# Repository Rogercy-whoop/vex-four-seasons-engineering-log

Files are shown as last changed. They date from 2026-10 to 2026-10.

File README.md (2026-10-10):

# VEX Robotics: four seasons, from newcomer to captain

**Four seasons of VEX V5 at my school, told through the robots, the code and the decisions.** I joined in Grade 9 carrying parts and filming matches, became the team's lead programmer in Grade 10, and have captained team **117V "Virtus Pro"** since Grade 11. This repository keeps the evidence: three generations of one robot and why each was replaced, every autonomous routine I wrote, the engineering notebook, the CAD, and what leading the team involved.

Yu Chen (Roger) · Grade 12 · Suzhou Foreign Language School (SFLS), China

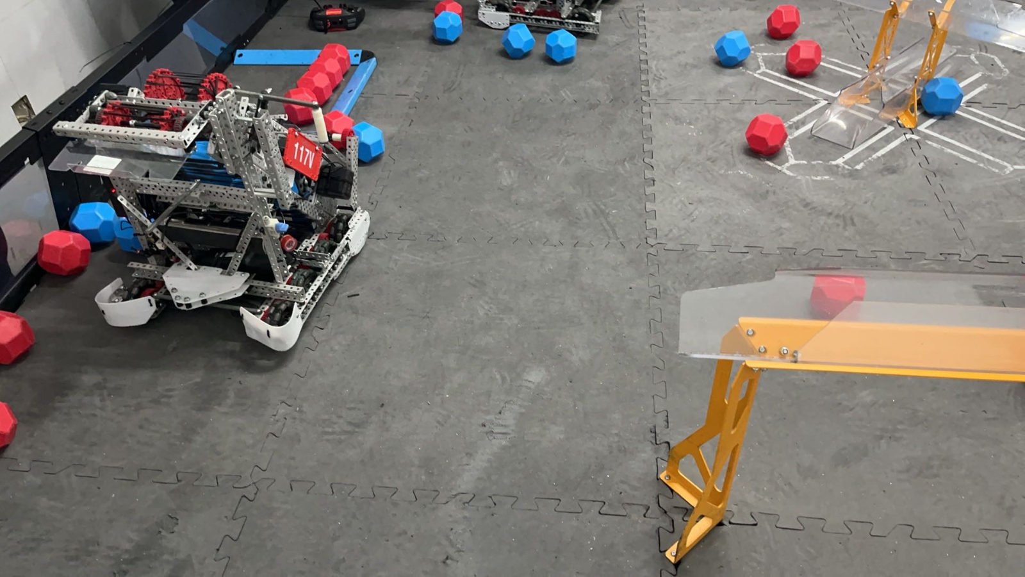
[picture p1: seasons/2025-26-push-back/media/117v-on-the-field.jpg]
117V's 2025–26 robot on the field


---

## Four seasons at a glance

| Season | Game | Team · my role | What we built | Highlight |
|---|---|---|---|---|
| 2023–24 · Grade 9 | *Over Under* | 117C · new member: parts, scouting, filming | Four versions of a catapult/climbing robot, V2.0 → V4.0 | Four robot versions in one season |
| 2024–25 · Grade 10 | *High Stakes* | 117C · **programmer → lead programmer**, CAD | Conveyor and lift-arm robot "V2.0" | 908 lines of autonomous code; a hand-written feedback controller for the lift arm |
| **2025–26 · Grade 11** | ***Push Back*** | **117V · captain, lead programmer, CAD** | **Three generations**: Gen 1 rollers → Gen 2 ramp → Gen 3 S-path | **Division 2 champion and overall runner-up**, VEX Robotics Invitational & VEX Academy National League (61 teams, 9 provinces); then the VEX World Championship China selection (Shanghai, Feb 2026) |
| 2026–27 · Grade 12 | *Override* | 117V · captain | In progress | Off-season: found why our drives never "arrived", and built a simulator now used by every team in the club |

## Start here

1. **[The 2025–26 design log](seasons/2025-26-push-back/design-log.md).** Three robots in one season. What each one got wrong, what we changed, and why, including the design we replaced even after it had won a competition.
2. **[The autonomous code](seasons/2025-26-push-back/code/README.md).** How the routes were planned, how they changed after real matches, and how the code grew and was cut back.
3. **[Reading our control template line by line](https://github.com/Rogercy-whoop/vex-auton-visualizer/blob/main/docs/FINDINGS.md)** (July 2026). The discovery that, all through 2025–26, every drive move had been ending on its timeout, never on arrival.

---

## The story

**Grade 9: learning the machine.** I joined the SFLS robotics club in 2023, on team 117C. My jobs were sourcing parts, scouting other teams and filming matches. That season the club's robot went through four versions (V2.0, V2.5, V3.0, V4.0), changing the drive speed, the scoring and climbing mechanisms, and the motor budget along the way. Each version was documented as a step-by-step build guide. → [2023–24](seasons/2023-24-over-under/README.md)

**Grade 10: writing the code.** In 2024–25 I became the team's programmer, then its lead programmer. Between March and May 2025 our autonomous code grew from 699 to 908 lines, with separate routines for attacking and defending, for qualification and final matches, and for skills. I also wrote a feedback controller of my own: a proportional loop that drives the lift arm to 37° from a rotation sensor. With our mentor I modelled the robot in SolidWorks. → [2024–25](seasons/2024-25-high-stakes/README.md)

**Grade 11: captain, and three robots.** In 2025–26 I captained 117V. We built **Gen 1**, found it could not store enough blocks and that its rubber-band rollers tangled with other robots, and replaced it with **Gen 2**: a new drivetrain, a rubber-wheel intake on a floating rail, double-row storage and a belt-and-paddle transfer. In August our club's sister team 117B took a robot of the Gen 2 design to the WRCT 2025 selection and won the high-school division; I helped them during development, in the pits and with their code. Watching that design compete showed us three problems: blocks leaking from the double row, an autonomous with no real advantage, and side-by-side jams. So we rebuilt ours as **Gen 3**, with a single S-shaped storage channel and rollers deliberately run at different speeds. In November, Gen 3 **won Division 2 and finished runner-up overall** at a national invitational in Suzhou. During that event I explained a disputed result to the referees on my own, in my second language; they ordered a rematch, and we won it. In February we competed at the VEX World Championship China selection in Shanghai. → [2025–26](seasons/2025-26-push-back/README.md) · [leadership, in my own words](leadership.md)

**After the season: finding out why.** After two seasons of tuning autonomous routines by trial and error, in July 2026 I read our coach's motion-control template line by line. I found that every drive move that season had been ending on its timeout, never on arrival. Then I built a simulator that runs our real code on a laptop; all four teams in the club now use it. → [vex-auton-visualizer](https://github.com/Rogercy-whoop/vex-auton-visualizer)

**Grade 12.** Captain again, for *Override*. The robot is paused while the team applies to university. → [2026–27](seasons/2026-27-override/README.md)

---

## Inside this repository

| | |
|---|---|
| **Design** | [2025–26 design log](seasons/2025-26-push-back/design-log.md) · [engineering notebook and design documents](seasons/2025-26-push-back/notebook/README.md) · [CAD](seasons/2025-26-push-back/cad/README.md) · build guides for [2023–24](seasons/2023-24-over-under/README.md) and [2024–25](seasons/2024-25-high-stakes/README.md) |
| **Code** | [2025–26 autonomous routines](seasons/2025-26-push-back/code/README.md) · [2024–25 code and the arm controller](seasons/2024-25-high-stakes/README.md#code) |
| **Leadership** | [What being captain involved, and what it changed in me](leadership.md) |
| **Who did what** | [ROLES.md](ROLES.md): my part, my teammates' parts, our mentor's |
| **Beyond VEX** | [How VEX led to my other projects](beyond-vex.md) |
| **Photos** | [Robot photos](media.md) |

## How this repository was made

The robots, CAD, code and decisions are the team's and mine, as broken down in [ROLES.md](ROLES.md). Our notebook and design documents are published as originals, in Chinese. The English translations and summaries, the page structure and the first drafts of the text were written with Claude, Anthropic's AI assistant, from those documents; see [AI-USE.md](AI-USE.md). Published with the agreement of my teammates and our mentor.

**Not included, on purpose:** other teams' code; the coach's motion-control template (linked, not copied); VEX's part library and field CAD.

**Licence:** code under [MIT](LICENSE); documents, notebooks, CAD and photos under [CC BY-NC 4.0](LICENSE-CONTENT.md).

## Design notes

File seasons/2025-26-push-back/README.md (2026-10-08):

# 2025–26 *Push Back* (Grade 11): team 117V, captain

**Division 2 champion and overall runner-up** at the 2025–26 VEX Robotics Invitational & VEX Academy National League (Suzhou, November 2025; 61 teams from 9 provinces). Then the VEX World Championship China selection (Shanghai, February 2026).

117V on the field

## The season

This was my first season as captain. Team 117V had six members, and I was the lead programmer: I wrote every autonomous routine. With our mentor I also built the robot's SolidWorks models.

We built three robots. **Gen 1** could not store enough blocks, and its rubber-band rollers tangled with other robots. **Gen 2** fixed both with a new drivetrain, a rubber-wheel intake on a floating rail, double-row storage and a belt-and-paddle transfer.

In August our club's sister team 117B took a robot of the Gen 2 design to the WRCT 2025 selection and won the high-school division. While upgrading our own robot to Gen 2, I helped them during development, in the pits and with their code. Watching the design compete showed us that the double row leaked blocks, the autonomous had no real advantage, and blocks jammed side by side. So we designed **Gen 3**: a single S-shaped channel, three rollers deliberately run at different speeds, and a PC plate that centres the robot on the goal. In November, Gen 3 won Division 2 in Suzhou and reached the final.

The full reasoning, decision by decision, is in the **[design log](design-log.md)**.

## In this folder

| | |
|---|---|
| [design-log.md](design-log.md) | Every design decision, Gen 1 → Gen 2 → Gen 3, with reasons and evidence |
| [code/](code/README.md) | The autonomous routines (C++): strategy, how they changed, how the code grew and was cut back |
| [notebook/](notebook/README.md) | The full engineering notebook, the season improvement record, the concept study and the build guides (originals in Chinese, summarised in English) |
| [cad/](cad/README.md) | Our custom SolidWorks parts |
| [media/](media/) | Renders and photos |

## Timeline

| When | What happened | Robot |
|---|---|---|
| Start of the season | Concept study and brainstorm; ramp robot chosen; Gen 1 built and tested | Gen 1 |
| Jul–Aug 2025 | Gen 2 built; its autonomous code written | Gen 2 |
| 16 Aug 2025 | WRCT 2025 selection: our sister team 117B wins the high-school division with a Gen 2-design robot; I helped in development, in the pits and with code. Three problems with the design found. | Gen 2 |
| 22–24 Aug 2025 | Huzhou invitational ([RE-V5RC-25-0863](https://events.vex.com/robot-competitions/vex-robotics-competition/RE-V5RC-25-0863.html)): 29th of 54 ([photos](../../media.md#huzhou-invitational-august-2025)) | Gen 2 |
| Aug–Nov 2025 | Gen 3 designed and built | Gen 3 |
| **21–23 Nov 2025** | **Suzhou: Division 2 champion, overall runner-up** (below) | Gen 3 |
| Dec 2025 – Jan 2026 | Autonomous routines refined; Kunshan event ([RE-V5RC-26-4036](https://events.vex.com/robot-competitions/vex-robotics-competition/RE-V5RC-26-4036.html)) | Gen 3 |
| 1–4 Feb 2026 | **VEX World Championship China selection**, Shanghai (科创青禾 全国VEX机器人精英赛暨VEX世锦赛中国选拔赛, [RE-V5RC-25-0839](https://events.vex.com/robot-competitions/vex-robotics-competition/RE-V5RC-25-0839.html)): 34th of 40 in our division | Gen 3 |

## Suzhou, 21–23 November 2025

*2025-2026 VEX 机器人邀请赛暨VEX学苑全国联赛* (VEX Robotics Invitational & VEX Academy National League), high-school V5, Suzhou Olympic Sports Center. The event was open to teams from across China, and its stated purpose was to select teams for the VEX World Championship China selection. **61 teams from 9 provinces and municipalities** took part, in two divisions; each division's elimination winner went to the final. Official record: [RE-V5RC-25-3593](https://events.vex.com/robot-competitions/vex-robotics-competition/RE-V5RC-25-3593.html).

**Qualification (Division 2, 31 teams):** 9th, 5 wins and 3 losses.

**Eliminations**, allied with team **14882Z**:

| Round | Opponents | Score |
|---|---|---|
| Round of 16 | 18964W + 1418C | **won** 94–20 |
| Quarterfinal | 93333C + 58888A | **won** 47–43 |
| Semifinal | 33398A + 1418A | **won** 46–38 |
| **Division 2 final** | 41999C + 3778D | **won** 56–15 |
| Final, match 1 | 18965J + 5138K | **won** 47–26 |
| Final, match 2 | 18965J + 5138K | lost 22–60 |
| Final, match 3 | 18965J + 5138K | lost 3–110 |

**Award: Tournament Finalists (runner-up).**

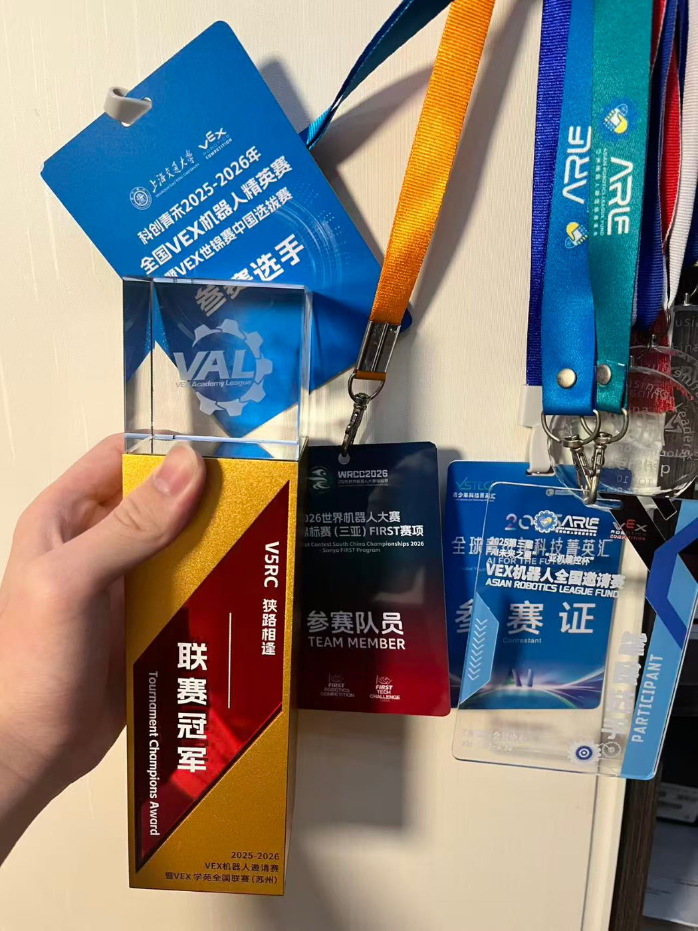
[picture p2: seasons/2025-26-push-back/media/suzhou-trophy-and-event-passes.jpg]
Our trophy from Suzhou, with passes from the season's events


*Our trophy from Suzhou, with passes from the season's events, including the VEX World Championship China selection in Shanghai and the Huzhou and Kunshan invitationals.*

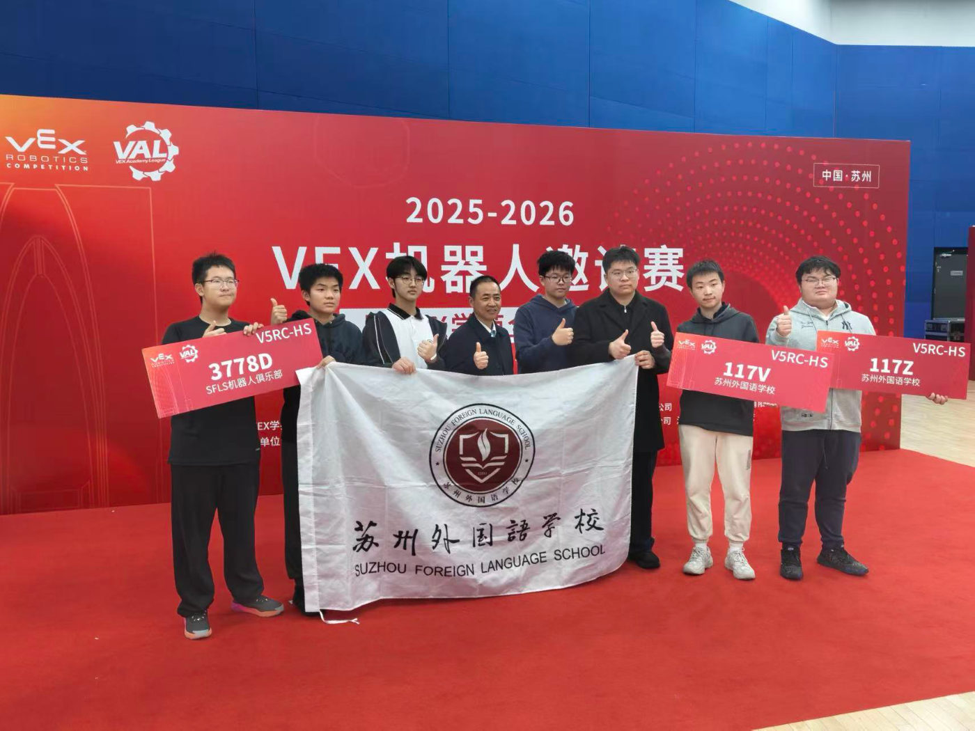
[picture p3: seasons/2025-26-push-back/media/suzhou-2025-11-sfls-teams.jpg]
SFLS teams at Suzhou


*Our school's teams at Suzhou: 117V with sister teams 117Z and 3778D, and our teacher.*

During the event, a result was disputed. I explained our case to the referees on my own, in my second language. They ordered a rematch, and we won it. (The online record shows only the final result of each round.) → [leadership](../../leadership.md)

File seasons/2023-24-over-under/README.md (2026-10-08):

# 2023–24 *Over Under* (Grade 9), team 117C

I joined the SFLS robotics club this year. As a new member I sourced parts, scouted other teams and filmed matches.

## One robot, four versions

The club's robot this season went through four versions. Each was documented as a step-by-step build guide in Feishu, with CAD renders, written by our mentor and the team.

| Version | What changed | Guide |
|---|---|---|
| **V2.0** | 360 rpm drive; built in a catapult variant and a climbing variant | [v2.0.pdf](build-guides/v2.0.pdf) |
| **V2.5** | Slower, stronger drive: 6 motors at 36:84 → 257 rpm on 6 wheels. Catapult on a 5:1 reduction, a 600 rpm direct-drive intake, a side climb, twin-piston wings. | [v2.5.pdf](build-guides/v2.5.pdf) |
| **V3.0** | A 55 W design | [v3.0.pdf](build-guides/v3.0.pdf) |
| **V4.0** | Climbing robot built around 5.5 W motors, on 4 in wheels | [v4.0.pdf](build-guides/v4.0.pdf) |

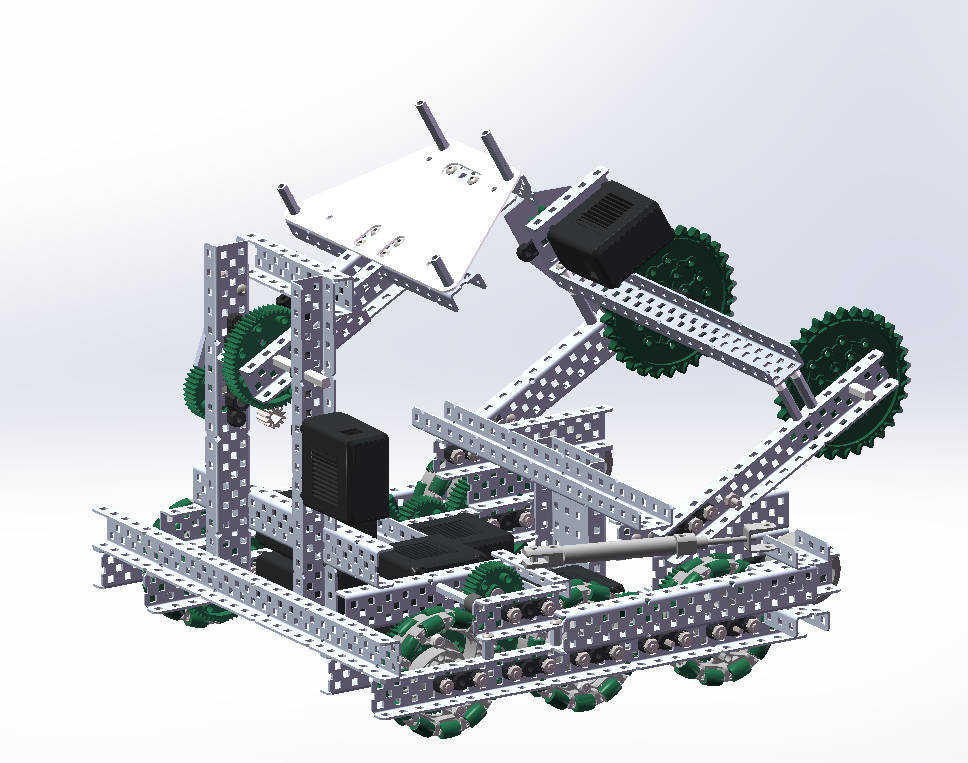
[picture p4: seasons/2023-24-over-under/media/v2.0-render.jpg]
V2.0
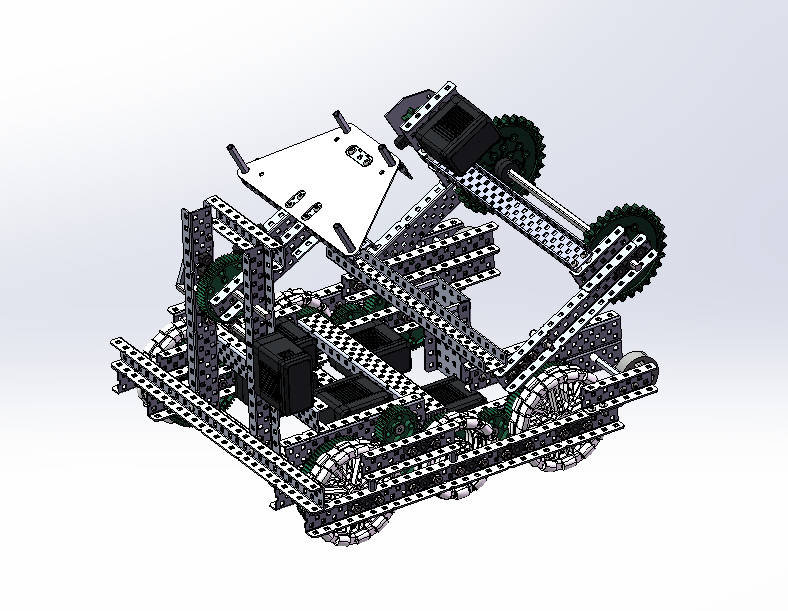
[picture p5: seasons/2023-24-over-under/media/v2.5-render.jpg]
V2.5
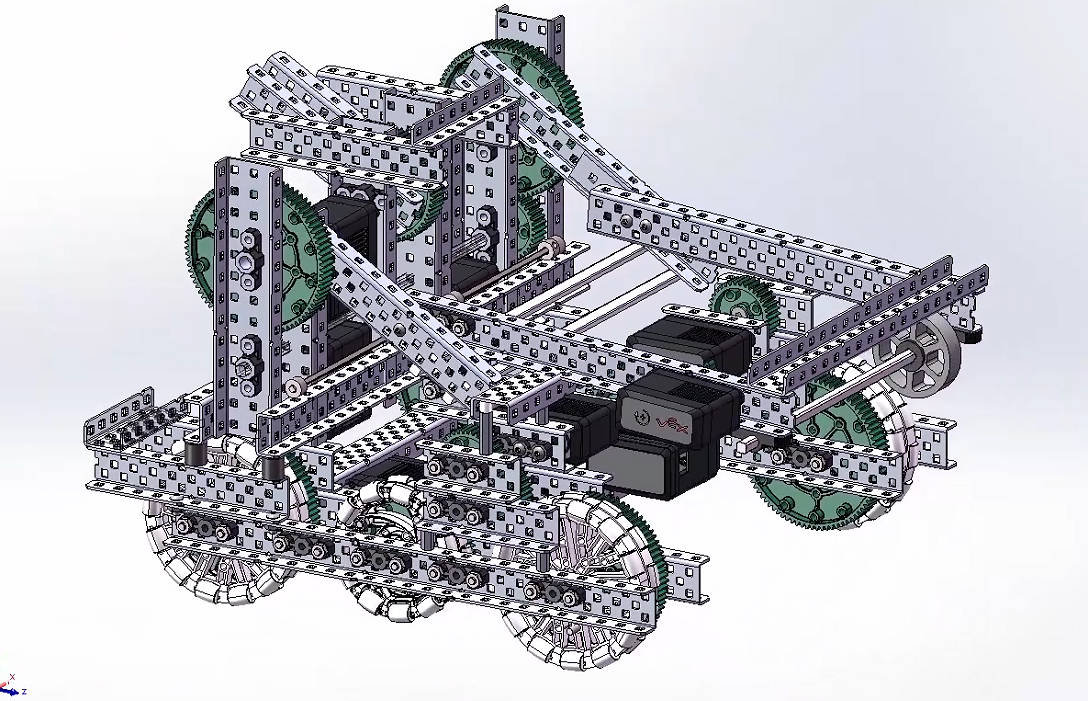
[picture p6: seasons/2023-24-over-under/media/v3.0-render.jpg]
V3.0
|  |  |  |
|---|---|---|
| V2.0 | V2.5 | V3.0 |

*The original guides were split into chapters (chassis, intake, climb, latch, launcher) for each variant. For this repository each version's chapters were merged into one PDF, and duplicate chapters shared by two variants were kept once. No content was changed.*

**Next season →** [2024–25: writing the code](../2024-25-high-stakes/README.md)

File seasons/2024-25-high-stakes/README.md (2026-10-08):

# 2024–25 *High Stakes* (Grade 10), team 117C

This was the season I started programming. I became the team's programmer and then its lead programmer, and with our mentor I modelled the robot in SolidWorks.

## The robot: "V2.0"

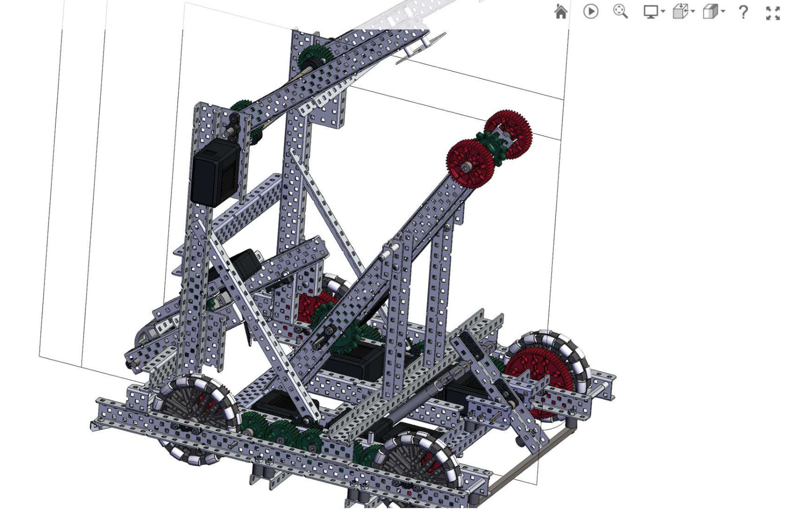
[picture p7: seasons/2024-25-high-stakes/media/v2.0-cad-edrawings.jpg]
V2.0 in SolidWorks eDrawings


*The "V2.0" model (SolidWorks, eDrawings web export, December 2024): a conveyor with hooks, a lift arm on 84T gears, and a 2 in rubber-wheel intake.*

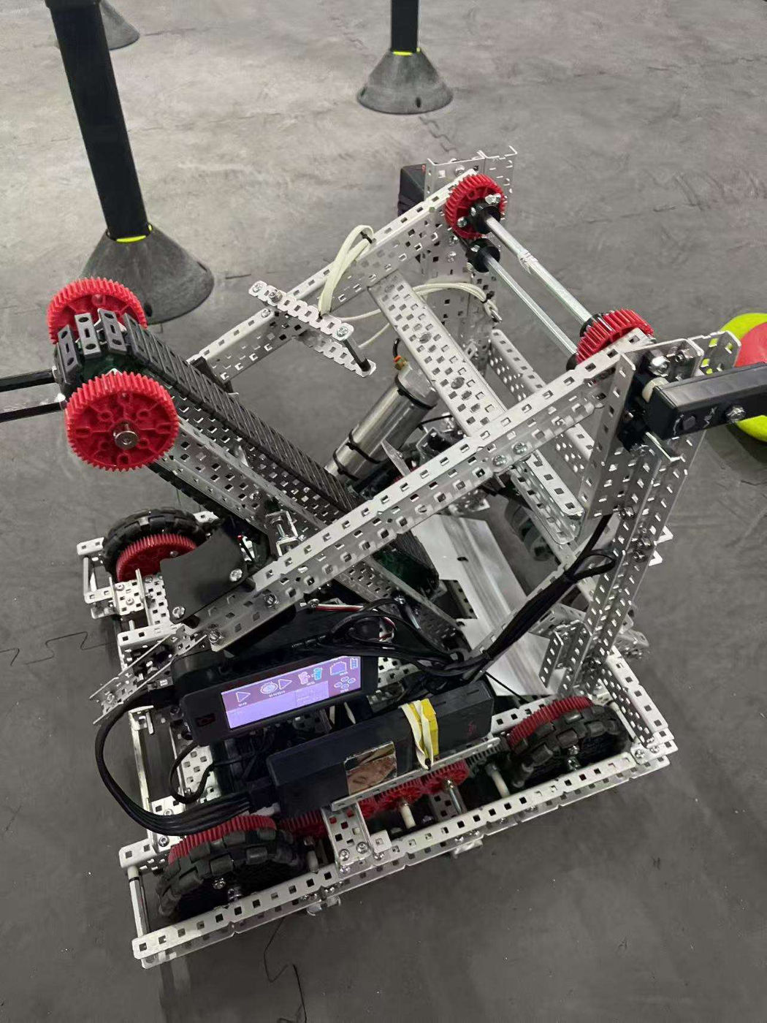
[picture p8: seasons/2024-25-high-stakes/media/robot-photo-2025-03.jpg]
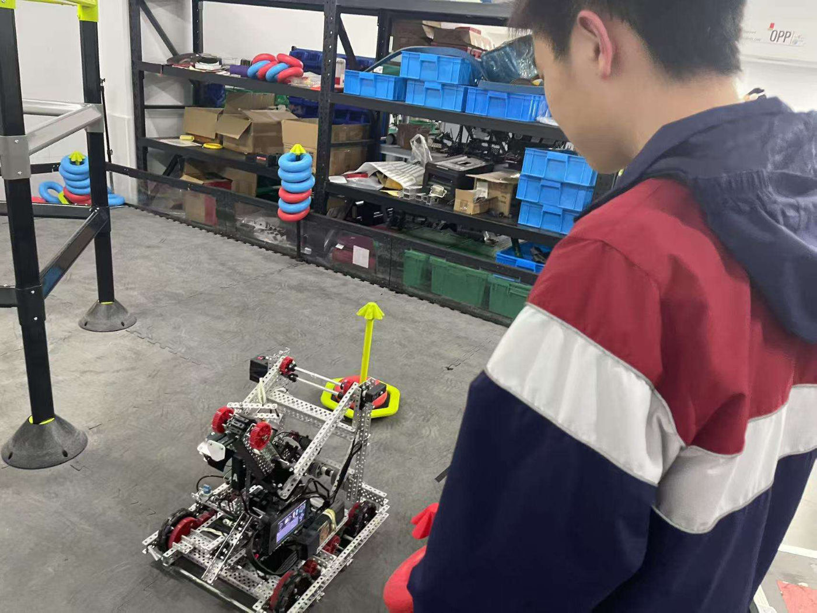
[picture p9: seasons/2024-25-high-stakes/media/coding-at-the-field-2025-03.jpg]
|  |  |
|---|---|
| *The built robot, March 2025* | *Testing code at the field, March 2025* |

The robot was documented as step-by-step build guides, co-written by our mentor, my teammates and me: [chassis](build-guides/01-chassis.pdf), [intake](build-guides/02-intake.pdf), [conveyor](build-guides/03-conveyor.pdf) and [lift arm](build-guides/04-lift-arm.pdf).

## Code

The project, "117c", grew from 699 lines of autonomous code in early March 2025 to **908 lines** by late May. Alongside left- and right-side routines, I wrote separate ones for attacking and defending, for qualification and final matches, and for skills.

| File | Lines | What it is |
|---|---|---|
| [`code/autons.cpp`](code/autons.cpp) | 908 | All the autonomous routines |
| [`code/autofunction.cpp`](code/autofunction.cpp) | 113 | Arm, intake and drive helpers |
| [`code/user.cpp`](code/user.cpp) | 95 | Driver control |
| [`code/main.cpp`](code/main.cpp) | | Competition set-up, the auton selector, and the arm controller below |

### A feedback controller for the lift arm

For the lift arm I wrote a proportional controller that reads a rotation sensor and drives the arm to 37° at the press of a button (`arm()` in [`main.cpp`](code/main.cpp)):

```cpp
error_a = t_angle - pre_angle;      // t_angle = 37 degrees
speed = 20 + error_a * p;           // p = 0.8: constant base power plus a correction proportional to the error
climb.spin(fwd, speed, pct);
...
if (fabs(pre_angle - t_angle) < 2.5 and Tarm > 350) break;   // within 2.5 degrees, after 350 ms
```

It also handles the sensor reading wrapping past 360° back to 0°.

**Next season →** [2025–26: captain, and three robots](../2025-26-push-back/README.md)

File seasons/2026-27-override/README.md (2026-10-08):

# 2026–27 *Override* (Grade 12): team 117V, captain

Work on this season's robot is paused while the team applies to university. This page will grow when it resumes.

## Between seasons

- **July 2026: reading the template.** After two seasons of tuning autonomous routines by trial and error, I read our coach's motion-control template line by line. I found that every drive move in 2025–26 had ended on its timeout, never on arrival, and that the odometry had never been switched on. → [FINDINGS.md](https://github.com/Rogercy-whoop/vex-auton-visualizer/blob/main/docs/FINDINGS.md)
- **August–October 2026: building the simulator.** It runs a team's real, unmodified code on a laptop and shows where each move actually ends, cutting each test from 5–10 minutes to about 2 seconds. All four teams in our club now use it. → [vex-auton-visualizer](https://github.com/Rogercy-whoop/vex-auton-visualizer)

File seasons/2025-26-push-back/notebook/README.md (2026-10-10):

# 2025–26 notebook and design documents

The originals are in Chinese and are kept complete and unedited. Each has an English summary below. To keep every file under 10 MB, the photos inside the PDFs were downscaled (longest side 1400 px) and re-saved as JPEG. Text, handwriting and drawings are untouched.

| File | What | Pages | Size | Written by |
|---|---|---|---|---|
| [2025-26-engineering-notebook.pdf](2025-26-engineering-notebook.pdf) | Engineering notebook (*工笔*), iPad handwriting | 20 | 9.4 MB (from 28.2) | The team |
| [2025-26-improvement-record.pdf](2025-26-improvement-record.pdf) | Season improvement record (*25-26赛季机器改进记录*), Gen 1 → Gen 2 → Gen 3 | 22 | 2.2 MB | Our mentor, my teammates and me |
| [2025-26-concept-study.pdf](2025-26-concept-study.pdf) | Concept study (*机型设计参考*) from the start of the season | 5 | 0.6 MB | Our mentor, my teammates and me |
| [build-guides/](build-guides/) | Step-by-step build guides for Gen 1 and Gen 2 | 2–25 each | 0.1–2.1 MB | Our mentor, my teammates and me |

## 1. Engineering notebook (*工笔*), summary

| Pages | Content |
|---|---|
| 1 | Cover: "117V Virtus PRO" with a line drawing of the robot |
| 2 | The six team members and their roles (see [ROLES.md](../../../ROLES.md)) |
| 3–7 | **Understanding the rules.** 88 blocks (preloads, match loads, field, loaders), goals and their capacities, scoring values, parking, the 5-second delayed scoring. **Motor budget:** total power ≤ 88 W, so the legal mixes of 11 W / 5.5 W motors are 8+0, 7+2, 6+4, 5+6, 0+16. The principle: use one motor for several jobs where possible, and don't add motors just to reach 88 W. Non-VEX parts (rope ≤ 6.35 mm, PVC sheet), the 18 in starting size, how WP/AWP/SP rankings work. The conclusion: *"autonomous matters most. Winning it eases the pressure on driver control and is the key to ranking."* |
| 8–9 | **Brainstorm.** Lift robot (simple, low centre of gravity, passes under the long goal; but unstable while scoring and drops stored blocks) vs "big stomach" robot (stores the most and is stable; but heavy and wide, and gets stuck turning between goals) vs **ramp robot** (agile, enough storage, front intake / rear scoring suits loader → long goal; but weaker grip and less pushing power). **Final choice: ramp robot.** It had no major weakness and balanced storage against agility. |
| 10–12 | **Problems → fixes:** long-goal alignment (a PVC plate plus an aluminium guide that self-centres the robot), middle-goal descoring, two-at-a-time jams (PVC funnel), blocks stopping on the loader plate (a zip tie) |
| 13–16 | **Robot design:** front intake / rear scoring; which roller turns which way for the high, middle and low goals; the first rubber-band rollers stored only 4 blocks; extra bands stiffened the top roller for the middle goal; band rollers → rubber wheels; chain moved inside and protected by a crossbeam |
| 17–20 | **Autonomous:** priorities (task > points > driver-control head start), the AWP task, left route v1 → v2 (long goal first), right route (drop the middle goal). See [code/README.md](../code/README.md#planning-the-15-seconds). |

**Third-party figures.** Pages 3–5 and 12 reproduce figures from the official VEX V5RC *Push Back* game manual, and pages 17–20 draw routes on a *Push Back* field image. They are used inside a student notebook to analyse the rules. They remain © VEX Robotics / REC Foundation and are not covered by this repository's licence. The official manual: [the REC Foundation knowledge base](https://v5rc-kb.recf.org/hc/en-us/articles/9652912628631-Game-Manual-and-Resources-for-VEX-V5-Robotics-Competition-Teams).

## 2. Season improvement record, summary

Gen 1 → Gen 2 → Gen 3 with SolidWorks renders and test photos. Summarised card by card in the [design log](../design-log.md).

## 3. Build guides

| File | Summary |
|---|---|
| [gen1-chassis.pdf](build-guides/gen1-chassis.pdf) (*V1.0 机器搭建*, 8 p) | Gen 1 chassis: **29 holes wide**, bearing and motor positions, wheel shaft stack-up |
| [gen1-intake.pdf](build-guides/gen1-intake.pdf) (*吸取搭建*, 16 p) | Gen 1 roller intake: 5.5 W + 11 W motors, shaft lengths (30.4 / 25.4 / 26.7 / 27.9 cm), sprocket and spacer order |
| [gen2-chassis.pdf](build-guides/gen2-chassis.pdf) (*v2.0 机器搭建*, 15 p) | Gen 2 chassis: **27 holes wide** between the 30-hole rails, 36T gears × 10, 3.25 in omni wheels × 4 |
| [gen2-intake.pdf](build-guides/gen2-intake.pdf) (*搭建intake*, 25 p) | Gen 2 intake: uprights, cut C-channels, PC plates, two sprocket stages, the "intake up" assembly, descore mount |
| [gen2-pneumatics.pdf](build-guides/gen2-pneumatics.pdf) (*气动装置搭建*, 7 p) | Side hook and loader pistons: drilling positions and lengths |
| [gen2-middle-goal-plate.pdf](build-guides/gen2-middle-goal-plate.pdf) (*中goal 板子制作*, 6 p) | Middle-goal PC plate: 90° bend at 30 mm, 30° bend at 15 mm, zip-tie holes |
| [gen2-sled.pdf](build-guides/gen2-sled.pdf) (*Sled 安装*, 2 p) | Sled mounting |

*简单底盘搭建* ("simple chassis") is the first half of *v2.0 机器搭建*, so it is not repeated.

## Not included

- *2025-2026 规则解读* (rules interpretation): a teaching handout made mostly of game-manual images, with nothing of ours to add. The official manual is linked above.

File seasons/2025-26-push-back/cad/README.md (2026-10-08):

# 2025–26 CAD (SolidWorks)

I built this season's SolidWorks models with our mentor. The renders in the [design log](../design-log.md) come from them.

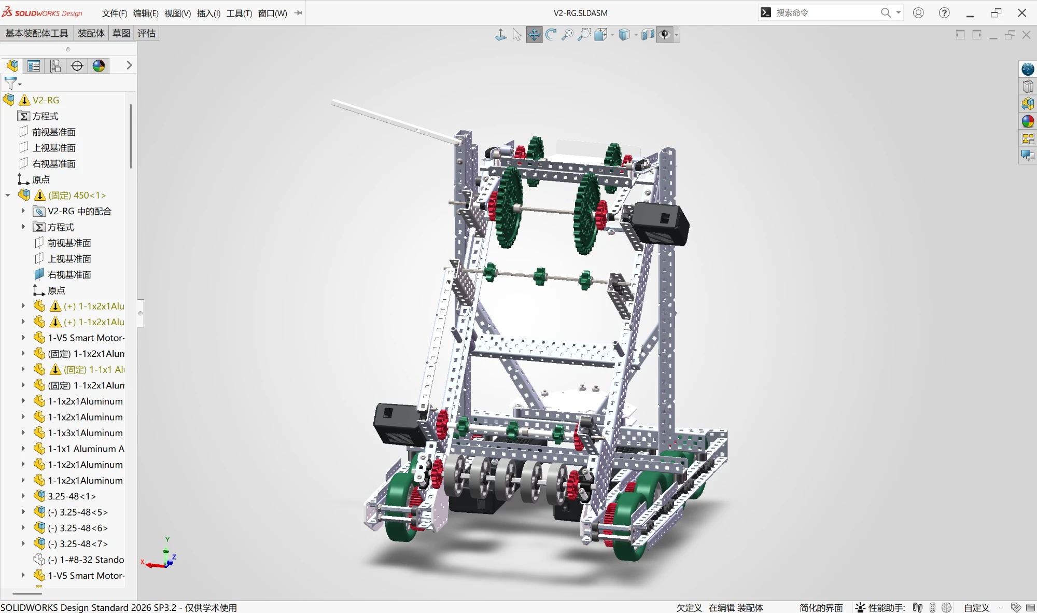
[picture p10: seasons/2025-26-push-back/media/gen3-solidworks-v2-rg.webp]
Gen 3 in SolidWorks


*The Gen 3 assembly (`V2-RG`) in SolidWorks.*

## Custom parts (in this repository)

These are the parts we drew ourselves, as opposed to VEX library parts. They open in SolidWorks or the free eDrawings Viewer.

| File | What it is |
|---|---|
| [`parts/对位板3.SLDPRT`](parts/) | **Centring plate, version 3.** The PC plate shaped from the goal's triangular notch, which replaced the aluminium triangle that centred badly ([design log](../design-log.md#lining-up-aluminium-triangle--pc-centring-plate)) |
| [`parts/sled-V2.SLDPRT`](parts/) | Sled plate, version 2 |
| [`parts/de.SLDPRT`](parts/) | Custom part |
| [`parts/侧钩粗轴.SLDPRT`](parts/) | High-strength shaft for the side hook |
| [`parts/17孔粗轴.SLDPRT`](parts/) | 17-hole high-strength shaft |
| [`parts/support.SLDPRT`](parts/) | Support |
| [`parts/窄轴承座.SLDPRT`](parts/) | Narrow bearing block |

## Assemblies

The full assemblies, including the Gen 3 robot (`V2-RG`) and the descore arm, are not committed. They are large (up to 28 MB), and they only open together with VEX's part library, which VEX distributes itself ([VEX CAD resources](https://v5rc-kb.recf.org/hc/en-us/articles/9636477857687-CAD-for-VEX-Robotics-Competition-Teams)).

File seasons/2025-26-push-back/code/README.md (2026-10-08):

# 2025–26 autonomous code

I wrote every autonomous routine for 117V this season, in C++ with VEXcode Pro V5. A second programmer on the team was learning and assisted me.

| File | Lines | What it is |
|---|---|---|
| [`autons.cpp`](autons.cpp) | 392 | Every autonomous routine, and the PID gains and exit conditions they run with |
| [`autofunction.cpp`](autofunction.cpp) | 82 | Helpers the routines call: collect and store, score high, score in the middle goal, stop |
| [`user.cpp`](user.cpp) | 83 | Driver control: drive, intake and scoring buttons, piston toggles |

**Not mine:** the motion-control template underneath (PID, drive functions, odometry) was supplied by our coach. It is not copied here; it is credited file by file in the simulator repo's [ATTRIBUTION.md](https://github.com/Rogercy-whoop/vex-auton-visualizer/blob/main/ATTRIBUTION.md).

## Planning the 15 seconds

The notebook sets the order of priorities for autonomous (NB p.17):

> **complete the autonomous task > score autonomous points > set up an advantage for driver control**

- **The task** (the AWP conditions) needs both robots: at least 7 alliance blocks scored, blocks in three goals, 3 blocks taken out of a loader, neither robot touching the park zone. We aimed to complete as much of it as our robot could.
- **Points:** the preload, 3 field blocks and 3 loader blocks guarantee 7.
- **The advantage:** whoever holds the control zone at the end of autonomous starts driver control ahead, so the route should take it (NB p.18).

## Changing the routes after real matches

Two changes came from competition, not from planning (NB p.19–20):

- **Left side: long goal first.** Our first left route scored the middle goal first. In real matches the opponent was scoring the same middle goal at the same time and interfered. The second version scores the long goal first and reaches the middle goal *after* the opponent, so it still scores there and can also knock the opponent's blocks out.
- **Right side: drop the middle goal.** On the right the middle goal is the low one. Scoring it means reversing the intake to push blocks out of the front, which cost too much time and was hard to do. So all 7 blocks go into the long goal: field blocks → loader → score → take the control zone.

| Routine | What it is |
|---|---|
| `zuo` | Left side, first version |
| `superzuo` | Left side, revised: long goal first |
| `lanyou` | Right side: all seven blocks into the long goal |
| `superyou` | Right side, alternative route |
| `skillszuo` | Skills: four loader visits, each emptied into a long goal |
| `test` | Single moves for tuning |

## How the code grew, and was cut back

| Version | Date | `autons.cpp` | |
|---|---|---|---|
| Gen 2 | Aug 2025 | 262 lines | First routines for the ramp robot |
| Gen 3, "strongest version" | 5 Dec 2025 | 559 lines | Many experimental routes tried side by side |
| Gen 3, competition | 3 Feb 2026 | **392 lines** | Pruned to the six routines above |

## What I found later

All season, the drive moves were tuned by adjusting their timeouts. In 2024–25 our code let a drive end when it arrived within 1.5 in. In 2025–26 that settle band was set to 0. In July 2026 I read our coach's template line by line and found what that meant: the "arrived" test can never be true at 0, so **every drive move in 2025–26 ended on its timeout, never on arrival**. The timeout, not the distance, decided how far the robot went. I also found that the odometry had never been switched on.

That investigation led to the simulator I built next. → **[vex-auton-visualizer / FINDINGS.md](https://github.com/Rogercy-whoop/vex-auton-visualizer/blob/main/docs/FINDINGS.md)**

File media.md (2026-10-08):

# Photos

## 2025–26 *Push Back*, team 117V

### Suzhou, November 2025

Trophy and event passes
*Our trophy from Suzhou, where we were Division 2 champions and overall runner-up, with passes from the season's events.*

SFLS teams at Suzhou
*Our school's teams at the Suzhou event: 117V with sister teams 117Z and 3778D, and our teacher.*

### The robot

117V on the field
*117V on the field, next to a loader.*

Gen 3 in SolidWorks
*The Gen 3 assembly in SolidWorks.*

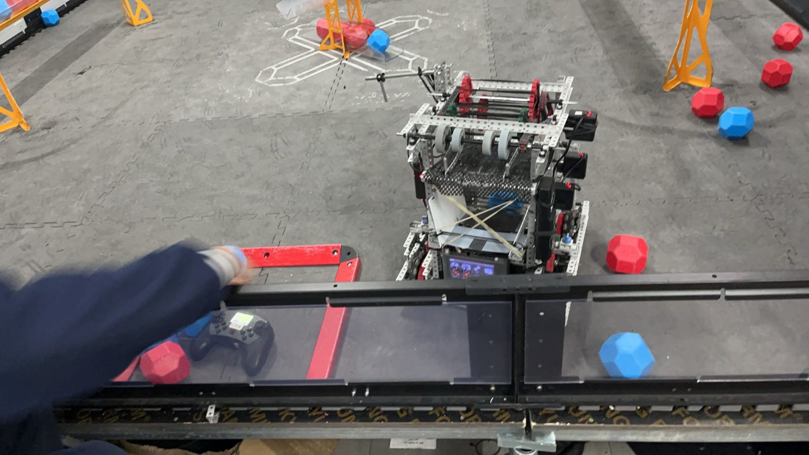
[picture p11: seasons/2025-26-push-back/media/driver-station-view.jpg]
From the driver station

*From the driver station during practice.*

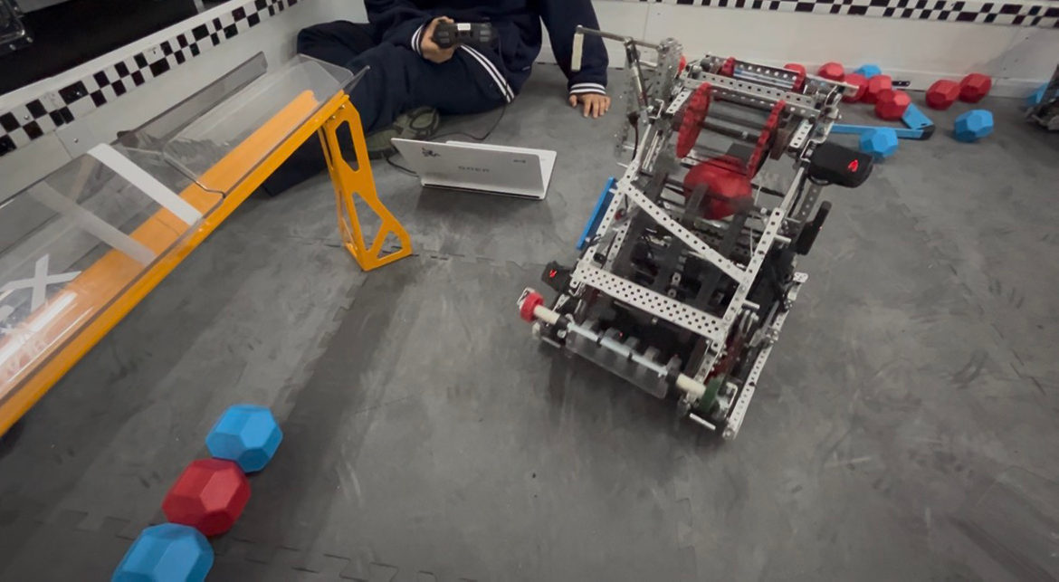
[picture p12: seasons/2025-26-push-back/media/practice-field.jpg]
On the practice field

*Testing on our practice field.*

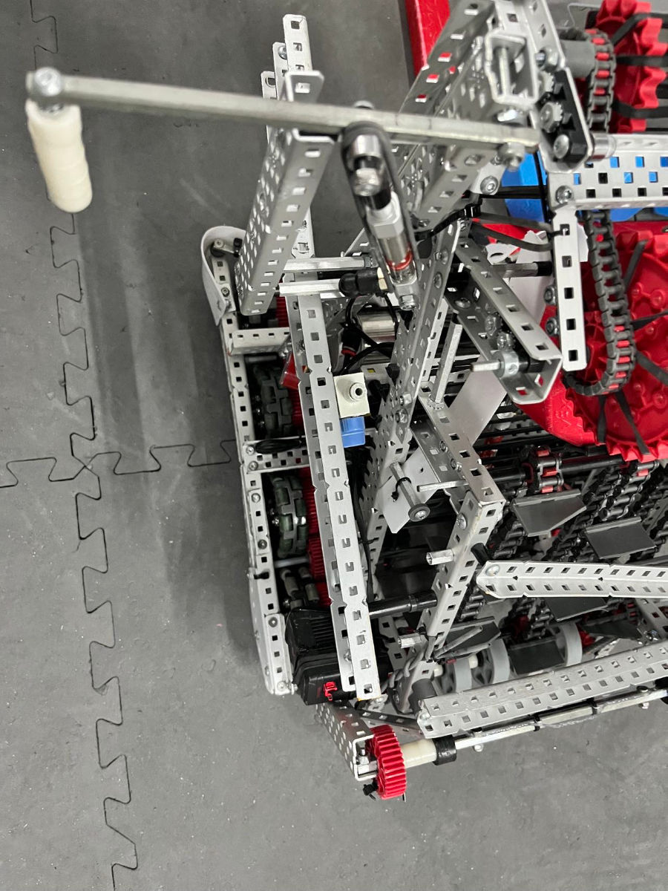
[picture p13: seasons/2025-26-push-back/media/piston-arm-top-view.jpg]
Piston-driven arm, top view

*Top view: the piston-driven arm, the chain run and the rollers.*

### Huzhou invitational, August 2025

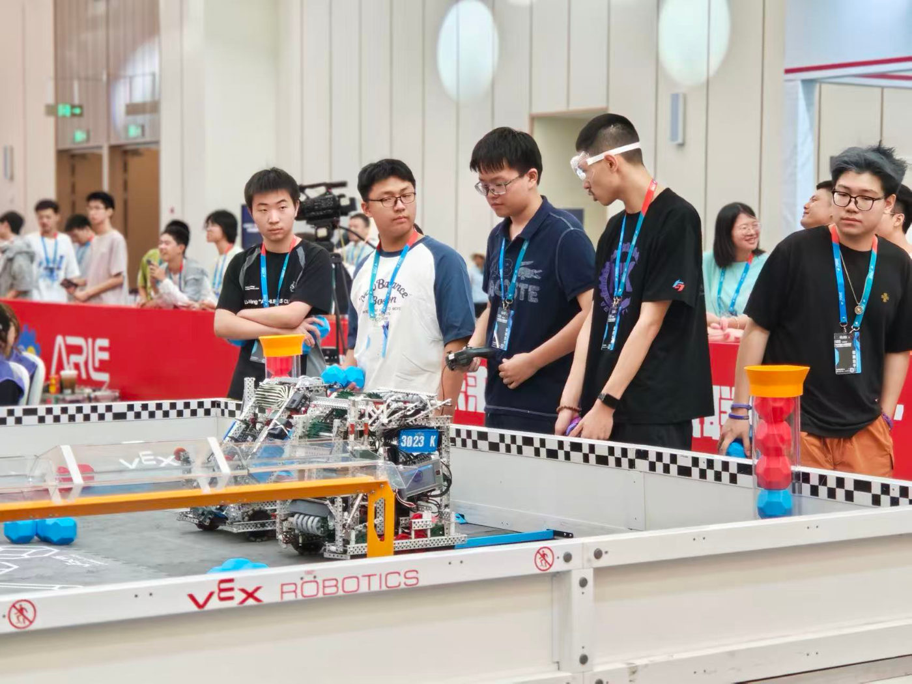
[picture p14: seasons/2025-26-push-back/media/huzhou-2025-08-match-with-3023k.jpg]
Match with 3023K

*A qualification match at Huzhou. 117V was allied with team 3023K (in front) in qualifier 12.*

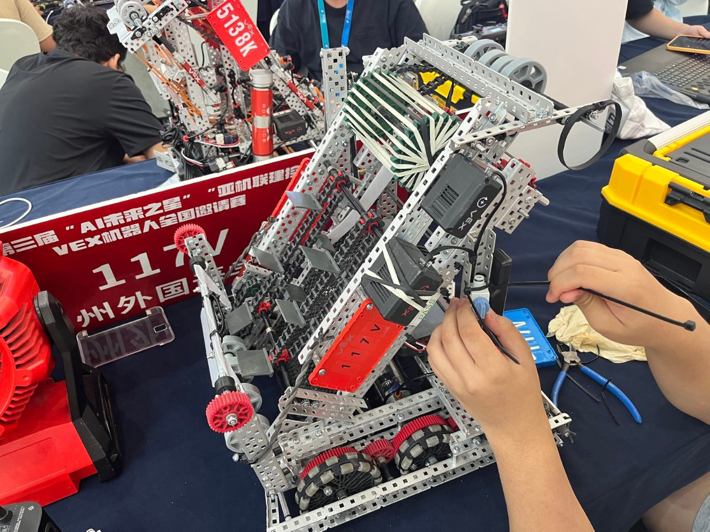
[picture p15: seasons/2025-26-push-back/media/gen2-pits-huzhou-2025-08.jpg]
Gen 2 in the pits at Huzhou

*Gen 2 in the pits at Huzhou.*

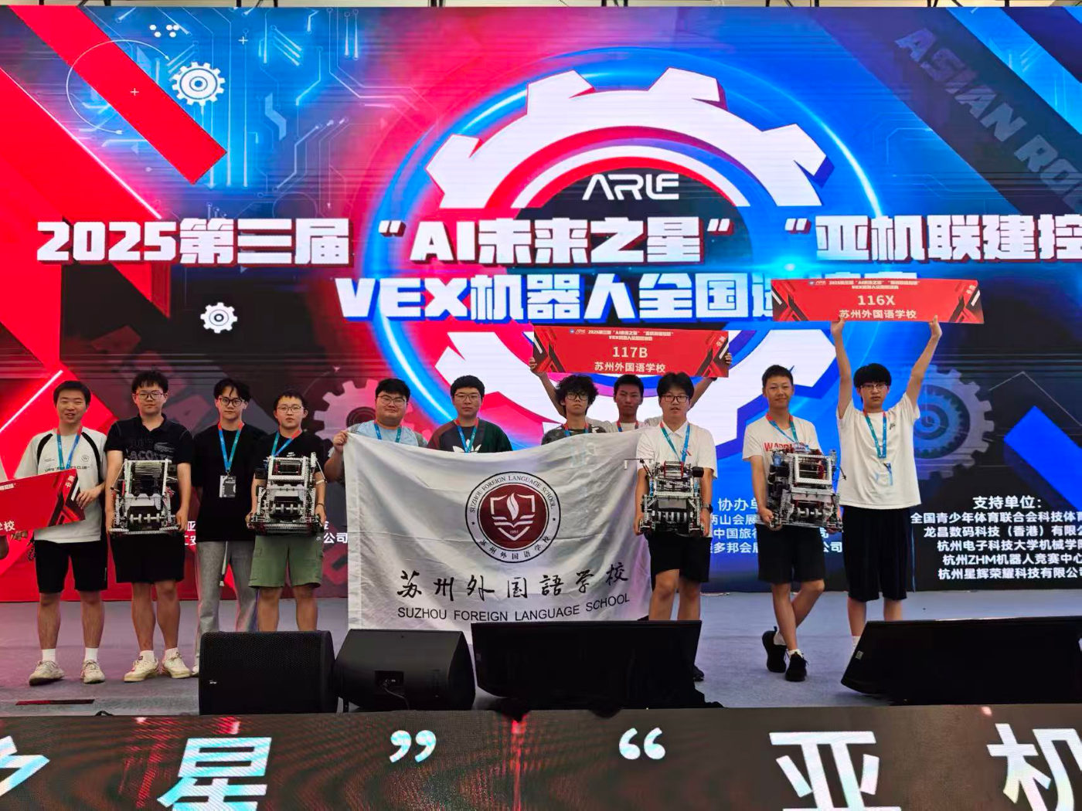
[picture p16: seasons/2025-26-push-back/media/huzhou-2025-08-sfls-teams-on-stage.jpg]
SFLS teams on stage at Huzhou

*Our school's teams on stage at Huzhou, with their robots.*

### WRCT 2025 selection, August 2025

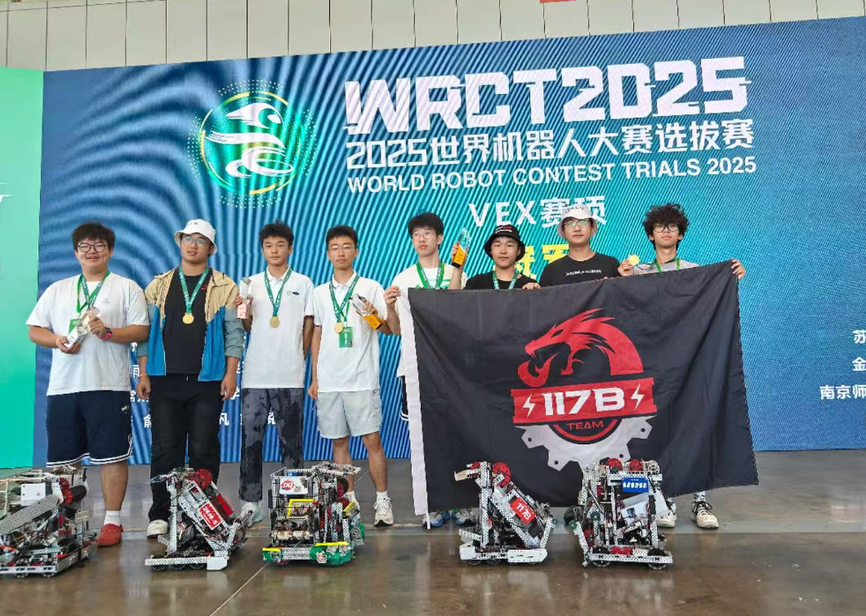
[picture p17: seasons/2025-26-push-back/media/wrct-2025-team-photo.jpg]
WRCT 2025 selection

*Our club's sister team 117B at the WRCT 2025 selection, 16 August 2025, where they won the high-school division. I helped them during development, in the pits and with code.*

More renders and test photos, with what each one shows, are in the [2025–26 design log](seasons/2025-26-push-back/design-log.md).

## 2024–25 *High Stakes*, team 117C

|  |  |
|---|---|
| *The "V2.0" robot, March 2025* | *The same robot in SolidWorks* |

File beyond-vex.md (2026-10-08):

# How VEX led to my other projects

Each of these began with a question VEX left me. The full stories are in their own repositories.

| Project | The VEX connection | Link |
|---|---|---|
| **VEX Auton Visualizer** (Aug–Oct 2026) | After two seasons of tuning autonomous routines by trial and error, I read our template and found that every 2025–26 drive move had ended on its timeout. I built a simulator that runs a team's real code on a laptop; all four teams in our club now use it. | [vex-auton-visualizer](https://github.com/Rogercy-whoop/vex-auton-visualizer) |
| **HIKROBOT internship** | I watched automated guided vehicles drift off their planned paths on worn concrete: the same drift I had blamed on my own code all season in VEX. | [JetRover README, "Why this exists"](https://github.com/Rogercy-whoop/jetrover-control-experiments#why-this-exists) |
| **JetRover control experiments** (self-funded) | I studied that drift properly on a robot I bought myself: PID on an ESP32 first, then a heading controller that keeps a robot straight when one side slips. | [jetrover-control-experiments](https://github.com/Rogercy-whoop/jetrover-control-experiments) |
| **TRI wall-climbing robots** | On the wall-climbing robots I tested at TRI, I met the same lesson as in my JetRover motor tests: a maximum rating is something a machine can *reach*, not something it can be held at. | [JetRover README, Stage 4b](https://github.com/Rogercy-whoop/jetrover-control-experiments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) |

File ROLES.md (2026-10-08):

# Who did what

Our 2025–26 engineering notebook (NB p.2) lists the team's six members with one label each:

| Member | Label in the notebook | English |
|---|---|---|
| 徐子凡 (Xu Zifan) | 操作 | Driver |
| **陈誉 (Chen Yu, me)** | **程序** | **Programming** |
| 陈邢晔 (Chen Xingye) | 程序 | Programming |
| 潘逸曦 (Pan Yixi) | 设计 | Design |
| 兰济成 (Lan Jicheng) | 设计 | Design |
| 戴钰轩 (Dai Yuxuan) | 搭建 | Build |

These were primary labels, not boundaries; on a six-person team building three robots in one season, roles overlapped. My label says *programming*, but I was also the captain, built the CAD with our mentor, and co-wrote the team's documents. This page sets out what I did each season, with the file that shows it.

## 2025–26 *Push Back* (Grade 11), team 117V: captain, lead programmer

| What | My part | Evidence |
|---|---|---|
| Autonomous routines | Wrote all of them: `zuo`, `superzuo`, `lanyou`, `superyou`, `skillszuo`, `test` | [`code/autons.cpp`](seasons/2025-26-push-back/code/autons.cpp), 392 lines |
| Mechanism helpers and driver control | Wrote them | [`autofunction.cpp`](seasons/2025-26-push-back/code/autofunction.cpp), [`user.cpp`](seasons/2025-26-push-back/code/user.cpp) |
| PID tuning | Tuned the gains and timeouts on the robot | `autons.cpp`, `default_constants()` |
| SolidWorks CAD | Built the models with our mentor, including the Gen 3 robot (`V2-RG`) and custom parts such as the centring plate | [`cad/`](seasons/2025-26-push-back/cad/README.md) |
| Engineering notebook and design documents | Co-wrote with my teammates and our mentor | [`notebook/`](seasons/2025-26-push-back/notebook/README.md) |
| Captaincy | | [leadership.md](leadership.md) |
| Help for our sister team 117B | Development, pit and code help when they won the WRCT 2025 selection | [design log](seasons/2025-26-push-back/design-log.md#chapter-2-learning-from-a-win) |

**My teammates:** 徐子凡 was our driver. 潘逸曦 and 兰济成 worked on design, and 戴钰轩 on building. 陈邢晔 was learning to program and assisted me.

**Our mentor**, the school's robotics teacher, built the SolidWorks models with me, and co-wrote the design documents and build guides.

**Not ours:**
- The motion-control template (`PID.cpp`, `drive.cpp`, `odom.cpp`, `util.cpp`) is our coach's. It is credited in the simulator repo's [ATTRIBUTION.md](https://github.com/Rogercy-whoop/vex-auton-visualizer/blob/main/ATTRIBUTION.md) and not copied here.
- The Gen 3 idea of piston-lifted double parking with a single storage channel came from watching team **16610A** ([design log](seasons/2025-26-push-back/design-log.md#chapter-2-learning-from-a-win)).

## 2024–25 *High Stakes* (Grade 10), team 117C: programmer → lead programmer

| What | Evidence |
|---|---|
| The team's code: project "117c", March → May 2025, `autons.cpp` 699 → 908 lines, plus a proportional controller for the lift arm | [2024–25 code](seasons/2024-25-high-stakes/README.md#code) |
| SolidWorks model of the "V2.0" robot, with our mentor | [screenshot](seasons/2024-25-high-stakes/media/v2.0-cad-edrawings.jpg) |
| Build guides, co-written with our mentor and teammates | [build-guides/](seasons/2024-25-high-stakes/build-guides/) |

## 2023–24 *Over Under* (Grade 9), team 117C: new member

Sourcing parts, scouting and filming matches, while the club's robot went through four versions ([build guides](seasons/2023-24-over-under/README.md)).

## 2026–27 *Override* (Grade 12), team 117V: captain

In progress.

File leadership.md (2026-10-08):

# What being captain involved

I have been captain of team 117V since Grade 11 (2025–26, and now 2026–27). The team has six members, plus our mentor. The events below come from our records; the reflections are in my own words.

## The disputed match at Suzhou

The whistle went and we had won. Then their robot kept moving. Its control system had died sometime in the last few seconds and nobody had noticed, so it kept driving straight through the goals we'd spent months learning to score. Our coach wasn't allowed onto the field, so I walked up to the referees on my own while the other alliance stood beside me telling a different version. There was no video. I told them, slowly and twice, in my second language, that the match had ended at the whistle and that their robot had kept moving after it, through the goals. They ruled on what they'd seen from where they were standing and ordered a rematch.

Back in the pit, our driver was already saying my autonomous should have banked more points, and he was right. So I said it louder than he did: my auton was so bad they'd given us free practice. Someone laughed. We won the rematch.

We went on to win the Division 2 final, and in the overall final we won the first match and lost the next two. → [the official record](seasons/2025-26-push-back/README.md#suzhou-2123-november-2025)

## Learning from a win

In August 2025 our club's sister team, 117B, took a robot of our Gen 2 design to the WRCT 2025 selection and won the high-school division. While upgrading our own robot to Gen 2, I helped them during development, in the pits and with their code. Watching the design compete showed us three things it could not do: it leaked blocks at the middle goal, its autonomous gave no real advantage, and blocks jammed side by side.

Our improvement record marks two team meetings as the season's turning points. The first set out what was wrong with Gen 1. The second, after WRCT, decided to design a third robot instead of keeping the design that had just won (IR p.1, p.14–15). Three months later, Gen 3 won Division 2 in Suzhou. → [design log](seasons/2025-26-push-back/design-log.md#chapter-2-learning-from-a-win)

## Owning the code

Our notebook lists two programmers, 陈邢晔 and me. I wrote every autonomous routine myself, mostly because explaining my reasoning felt slower than just typing it. He was still learning, and mostly assisted me. What I learned is that a team where only one person understands the autonomous is a team with a single point of failure, and that person was me. Leading meant explaining why a route was ordered the way it was, not only shipping the code.

The routes changed after real matches: the left side was reordered to score the long goal first, and the right side dropped the middle goal entirely (NB p.19–20). By December the code had grown to 559 lines of experiments, and I cut it back to the six routines we actually used. → [code](seasons/2025-26-push-back/code/README.md)

## Writing things down, and building for the whole club

Our robots were documented as step-by-step build guides, written by our mentor, my teammates and me, and the team kept an engineering notebook, a season improvement record and a pre-match checklist. → [notebook and guides](seasons/2025-26-push-back/notebook/README.md)

After the season I built a simulator that runs a team's real autonomous code on a laptop, and designed it so that every team in our club could use it with their own robot. All four teams (117V, 11117V, 116X-323 and 3778W) now do. → [vex-auton-visualizer](https://github.com/Rogercy-whoop/vex-auton-visualizer)

## What I would do differently

I'd open the control template on day one and read it with the whole team. For two seasons we tuned how far the robot drove by feel, and only when I finally read the code line by line did I find that, all through 2025–26, every drive move had ended on its timer, never on arrival. Nobody was hiding that. We just never looked.

I'd also stop keeping the autonomous to myself. Writing every routine made me the bottleneck, and when one failed, everyone waited for me. Next time, the newest member would own one small routine from the first week, with me reviewing it, not rewriting it.

## What changed in me

In Grade 9 I sourced screws, assembled other people's designs and filmed matches from the stands. I was quiet and easy to hand things to. Later, once I was writing the code, when an autonomous run failed the blame found me quickly, because I wasn't going to argue back.

None of that was a rule. It was an arrangement, and it changed when I stopped waiting to be given things. I practised driving until I could justify asking for the second controller. As captain, I stood in front of referees alone in my second language. And at an away competition I noticed a Grade 10 boy by the barrier with a camera, waiting for a gap in the noise that was never going to come. I knew that look, because it had been mine. So I handed him a broken intake and walked away.

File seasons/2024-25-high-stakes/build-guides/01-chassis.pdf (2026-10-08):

# 01 底盘搭建

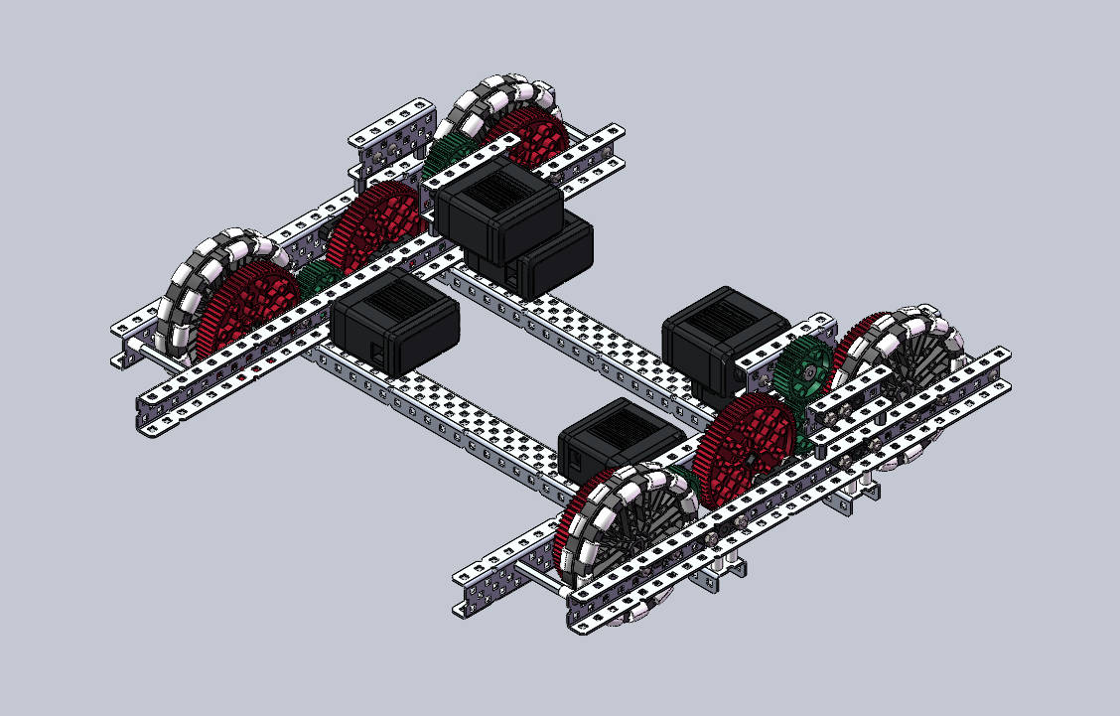
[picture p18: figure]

## 铝件加工

窄C | 32格 | 4个
窄C | 29格 | 2个
窄C | 6格 | 2个
窄C | 5格 | 2个
窄C | 32格及以上 | 2个

## 1.1外侧29格窄C安装轴承座×2

ps：4个安装在内侧，中间安装在外侧

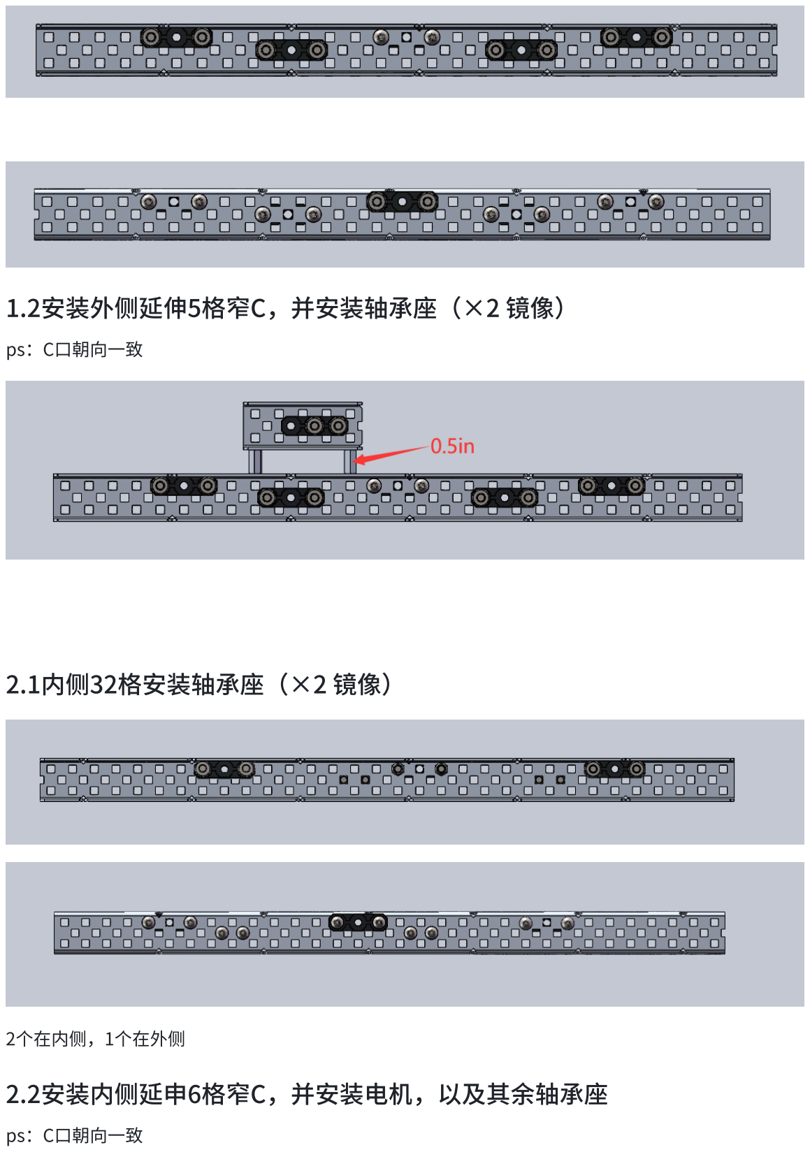
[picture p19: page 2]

## 1.2安装外侧延伸5格窄C，并安装轴承座（×2 镜像）

ps：C口朝向一致

## 2.1内侧32格安装轴承座（×2 镜像）

2个在内侧，1个在外侧

## 2.2安装内侧延申6格窄C，并安装电机，以及其余轴承座

ps：C口朝向一致

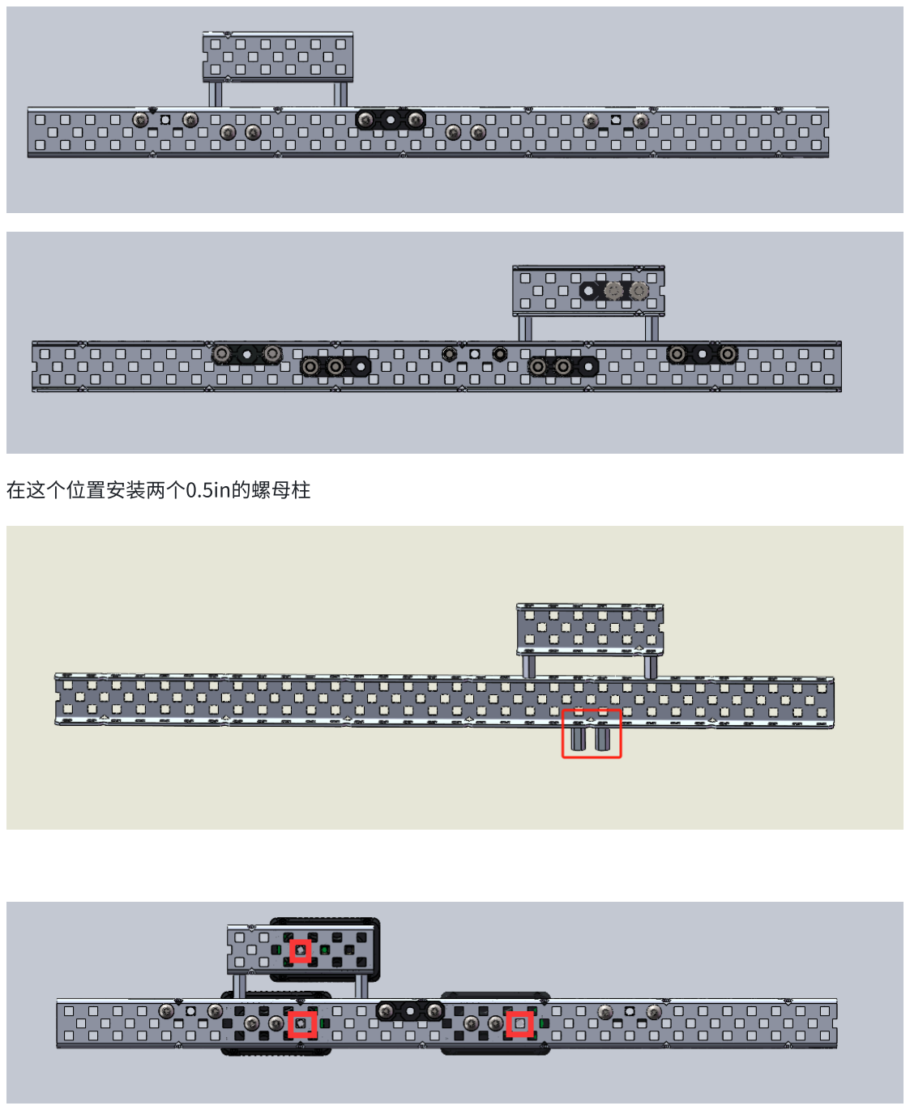
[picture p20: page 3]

在这个位置安装两个0.5in的螺母柱

## 3.1安装框架

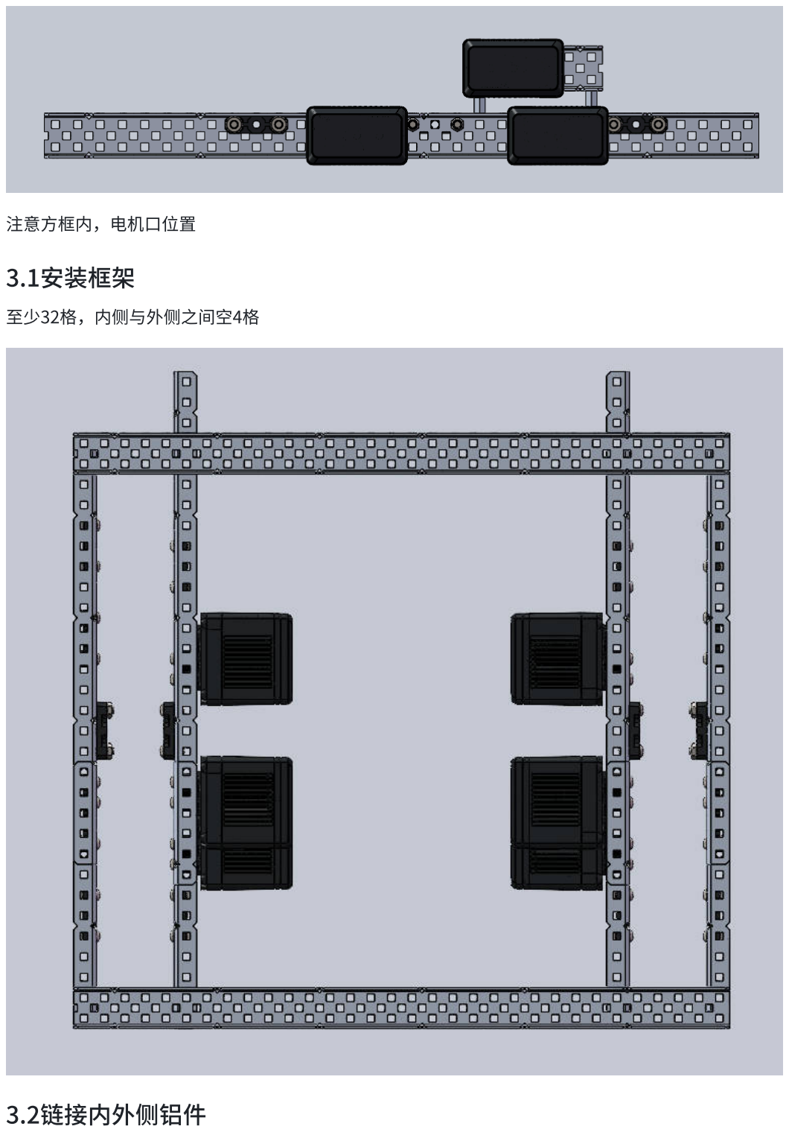
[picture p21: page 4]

注意方框内，电机口位置

至少32格，内侧与外侧之间空4格

## 3.2链接内外侧铝件

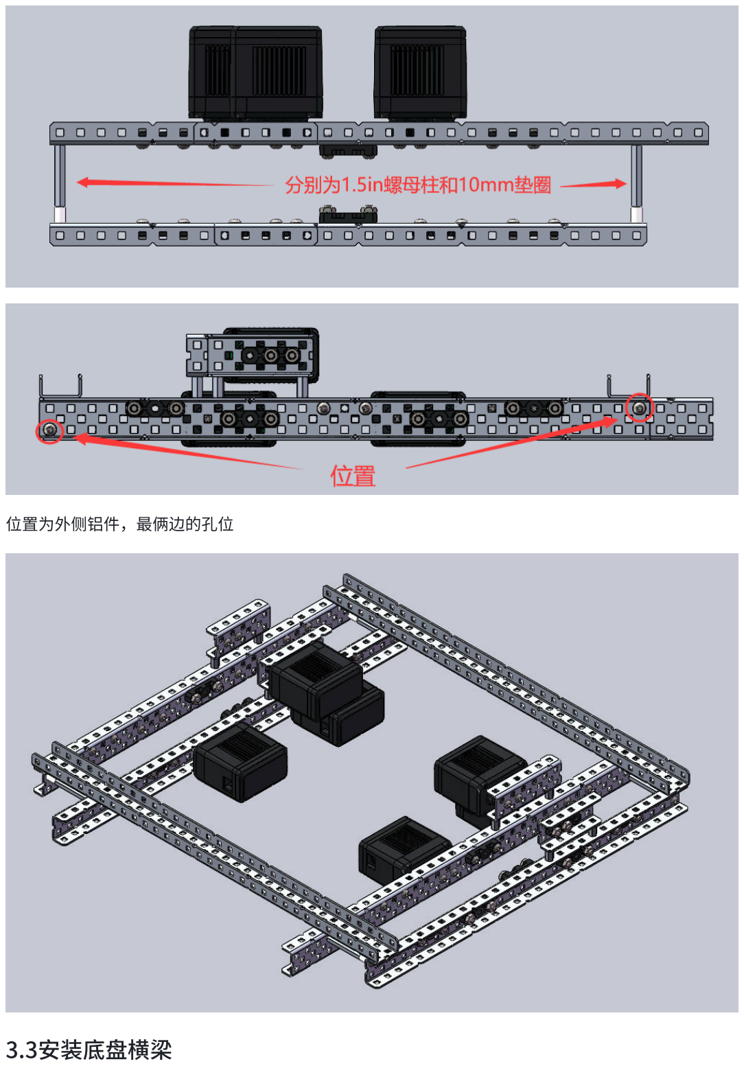
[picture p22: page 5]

位置为外侧铝件，最俩边的孔位

## 3.3安装底盘横梁

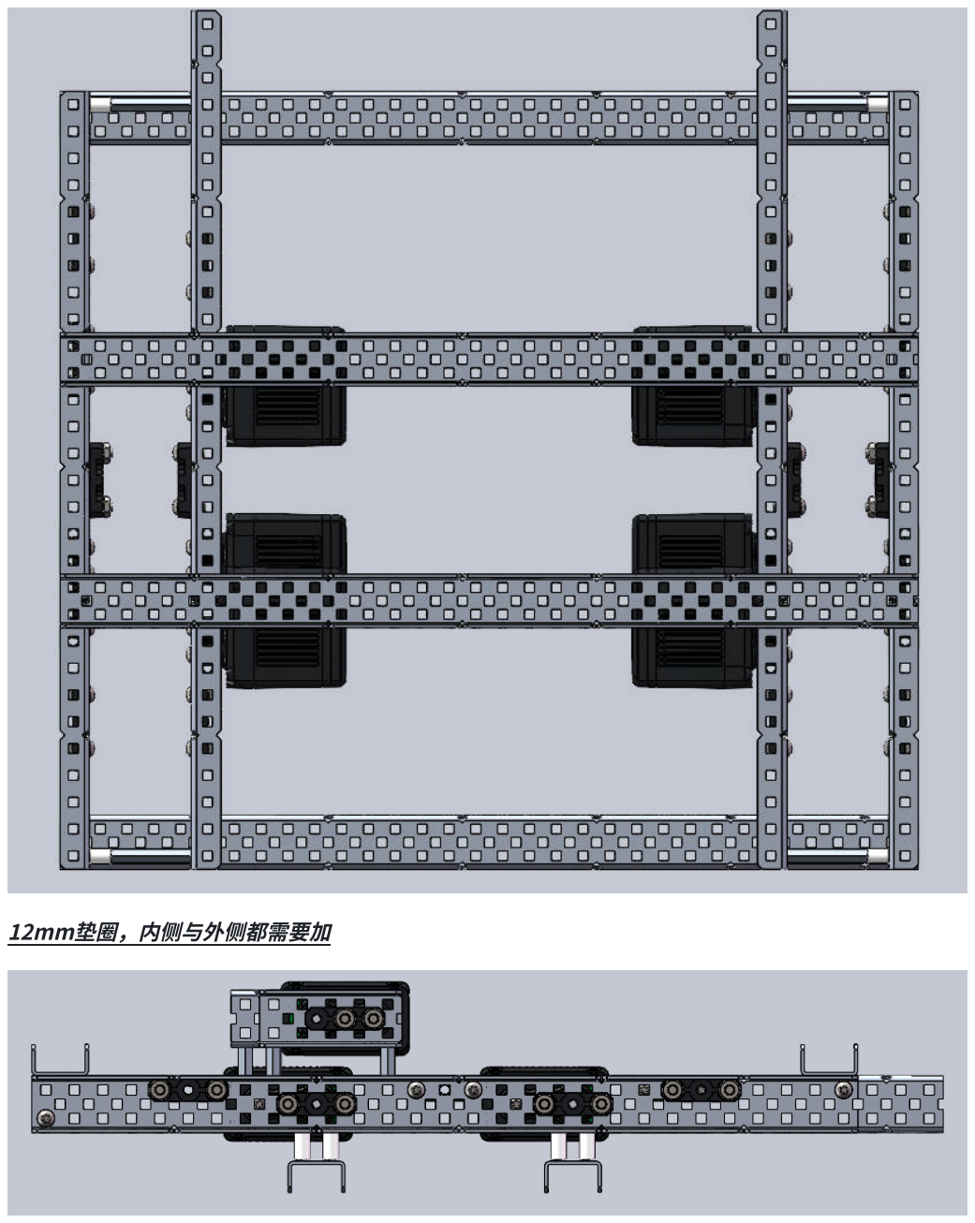
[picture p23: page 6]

12mm垫圈，内侧与外侧都需要加

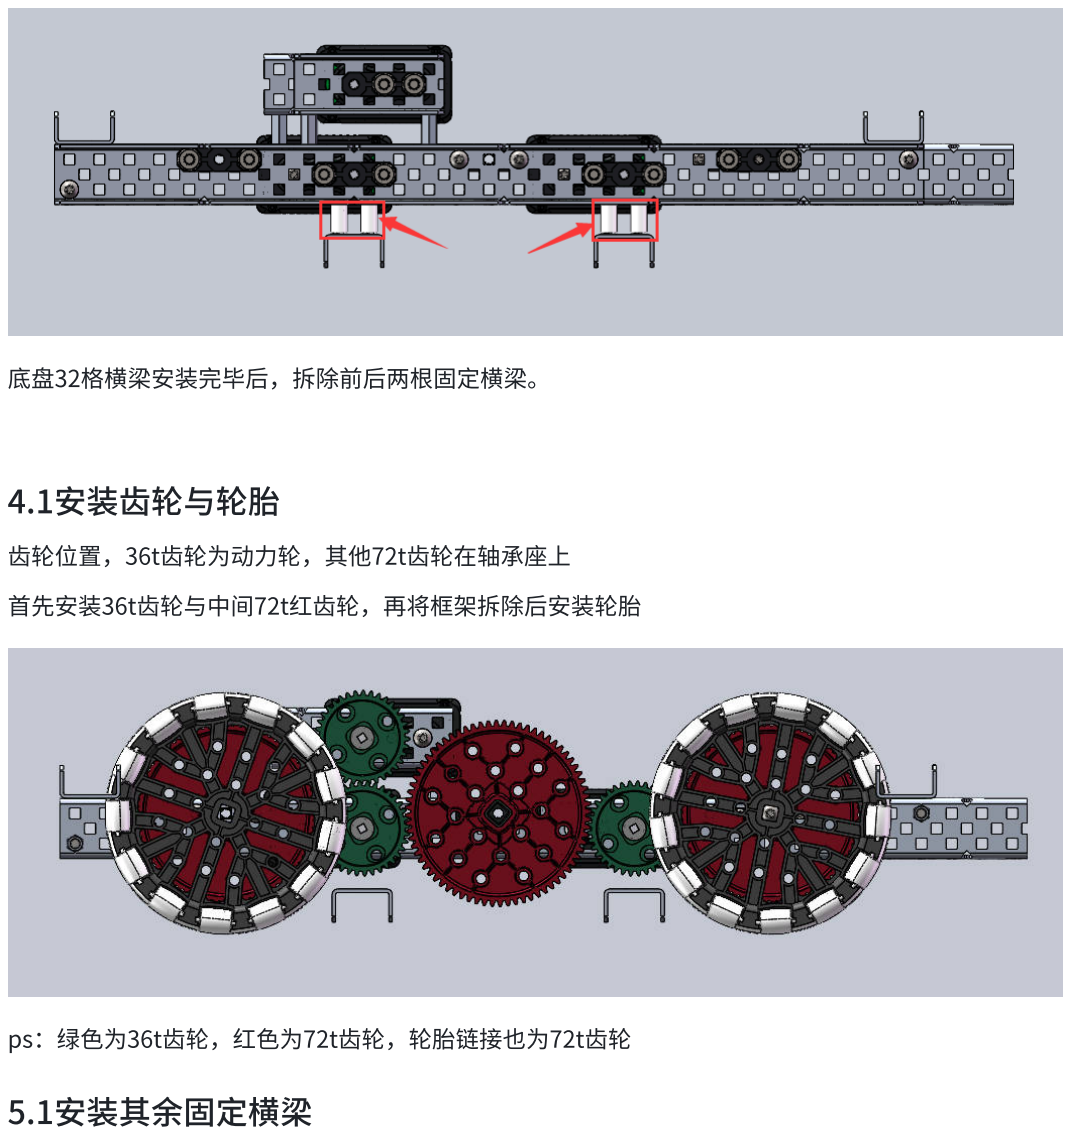
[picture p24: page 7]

底盘32格横梁安装完毕后，拆除前后两根固定横梁。

## 4.1安装齿轮与轮胎

齿轮位置，36t齿轮为动力轮，其他72t齿轮在轴承座上

首先安装36t齿轮与中间72t红齿轮，再将框架拆除后安装轮胎

ps：绿色为36t齿轮，红色为72t齿轮，轮胎链接也为72t齿轮

## 5.1安装其余固定横梁

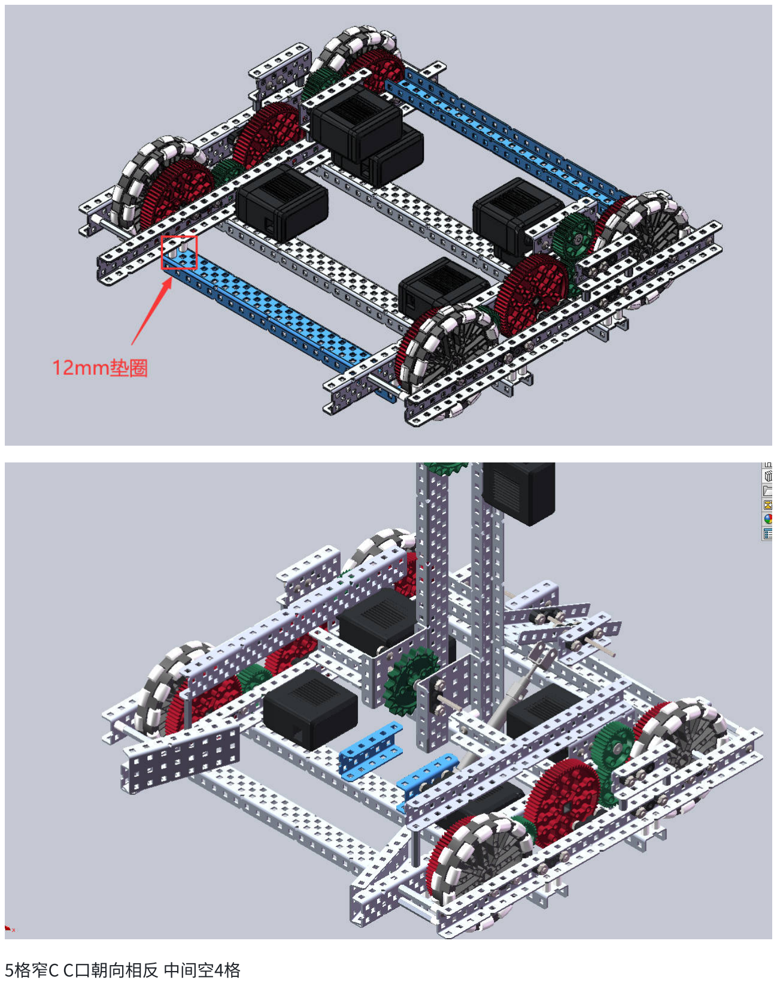
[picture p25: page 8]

5格窄C C口朝向相反 中间空4格


## 6.1安装夹子

10格中C与2个4格窄C

4格窄C c口朝外 如图所示横梁居中安装 相距4格，垫圈为14mm


10格中C内侧装轴承座，上边留4格，下边留3格


安装轴承座并安装细轴

7.1

准备2根20格窄c与1.5in螺母柱

安装在内侧低盘，第六个孔为螺母柱位置


10格窄C居中安装

## 抓取引导结构安装

准备2根8格的窄C，按照如图所示安装


安装孔位2：


## 8.1 前后外八

前外八，8格中C×2

中C与窄C c口朝向相对 只上一颗螺丝


后外八，10格窄C×2


4颗螺丝位置 空隙加垫圈

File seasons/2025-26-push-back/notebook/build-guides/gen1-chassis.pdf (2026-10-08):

# V1.0 机器搭建

## 铝件尺寸

窄C 30格 | 2
窄C 7格 | 2
窄C 29格 | 2
中C 29格 | 1
1*1L 6格 | 4
窄C 25格 | 2

## 安装外侧轴承座

安装数量：2个


## 安装电机侧


安装数量：2个（镜像）

安装3个1in的撑柱

## 安装框架

使用底盘固定支架，将底盘左右链接在一起，机器总宽是29格宽


在车头位置安装固定件

## 安装上侧轴承座

安装机器外边 6孔窄C 以及轴承座 轴承座位置如图


安装机器内边的 25孔窄C，然后安装上置电机 电机与轴承座在同一孔

安装29格窄C 作为横梁


## 安装车轮

齿轮和轮子中间的垫圈是8mm，用1.5in螺丝链接在一起


穿轴

从左往右数 0.375in垫圈 + 车轮 + 限位杯+ 0.125in垫圈

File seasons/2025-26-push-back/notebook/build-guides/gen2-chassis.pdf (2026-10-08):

# v2.0 机器搭建


## 安装框架

准备30格窄C*2 29格窄C*2


29格与30格为一边，C口朝向相反，中间隔4格，固定在框架内，29格窄C为内，30格为外

箭头方向为前。


总宽为27格（30格窄C到30格窄C距离27）

## 安装27格横梁

准备27格窄C*2、12格1*1L×2

中间横梁朝上，后方横梁朝后

垫圈为0.5in

后方窄C所有垫圈都安装


中间窄C只安装外侧垫圈

安装12格1*1L，安装在29格窄C上


## 安装轴承座


从头往后数第8格

圆圈位置安装螺丝，垫0.5in垫圈

左边为前，右边是后

首先安装内侧轴承座，注意螺丝安装位置

其次安装电机，圆圈为齿轮箱位置不安装螺丝，方框wei固定点位，注意电机安装方向

## 安装前后固定


最后安装外侧轴承座，同样注意螺丝安装位置

前固定，自锁螺母+1.5in螺母柱+8mm垫圈

准备7格中C*2



固定安装后，拆除框架



## 安装齿轮与万向轮

准备36T齿轮*10 3.25in万向轮*4


## 安装车轮装配件

螺丝长度：1.5in

垫圈厚度：0.25in螺丝 + 1mm垫片



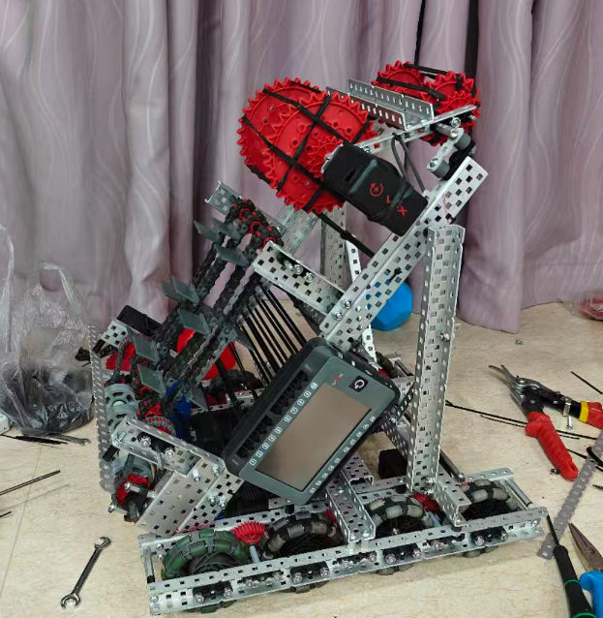
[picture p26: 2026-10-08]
seasons/2025-26-push-back/media/gen2-robot-photo.jpg

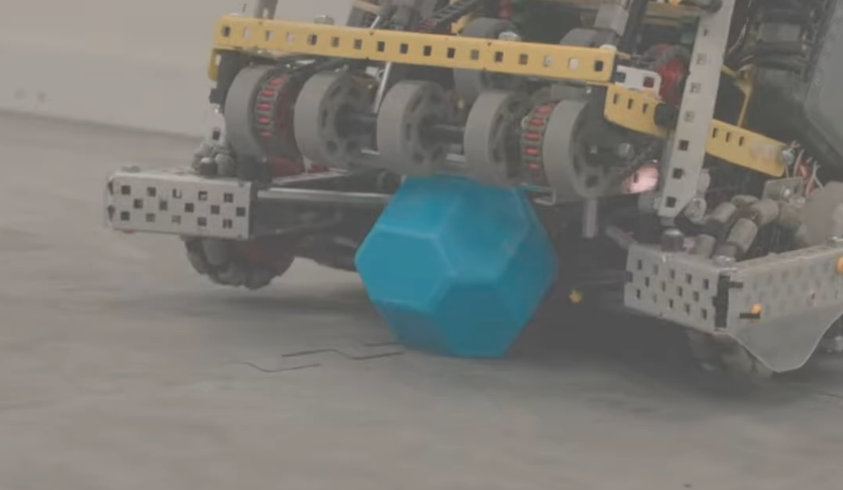
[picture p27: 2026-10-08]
seasons/2025-26-push-back/media/gen3-robot-photo-blurred.jpg

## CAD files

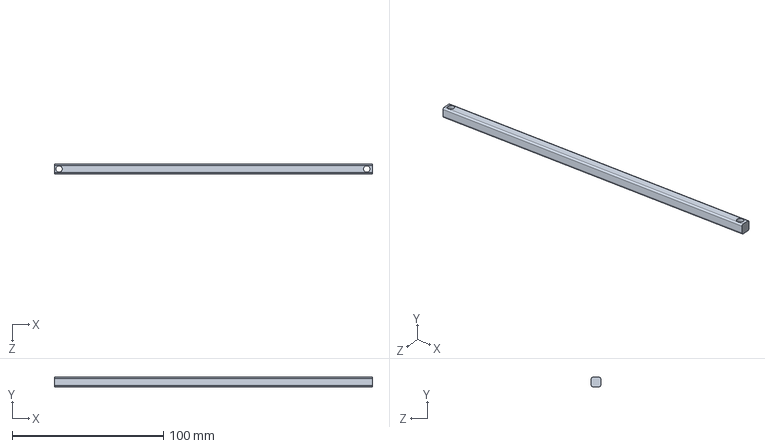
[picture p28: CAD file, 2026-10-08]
seasons/2025-26-push-back/cad/parts/17孔粗轴.SLDPRT
210.0 x 6.32 x 6.32 mm

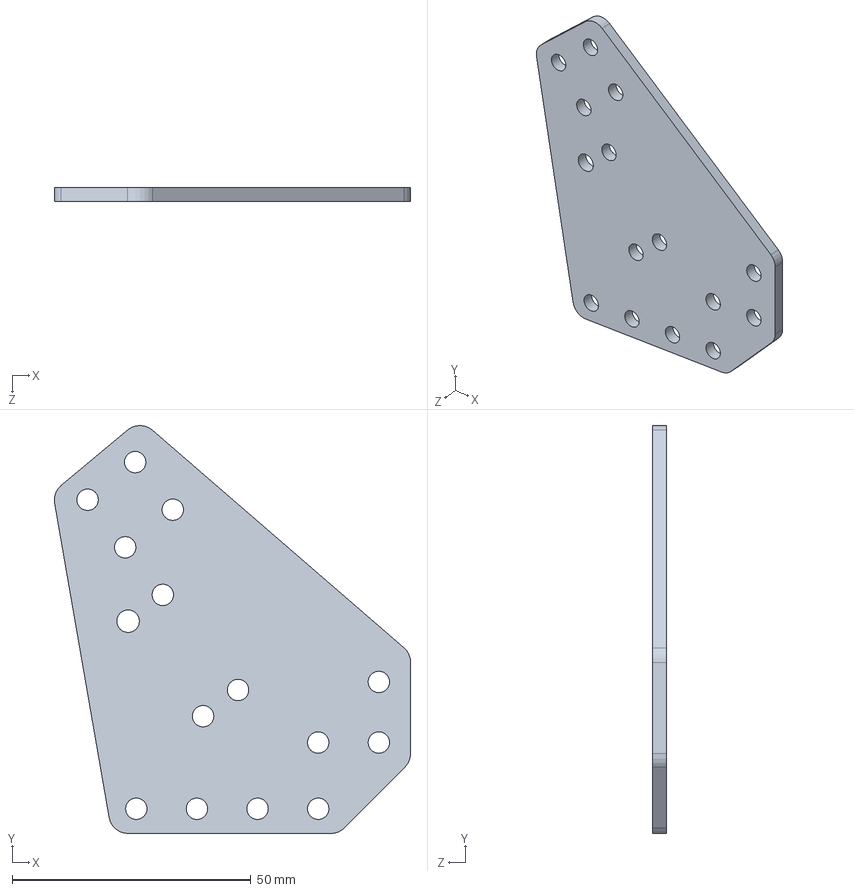
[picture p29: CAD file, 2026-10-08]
seasons/2025-26-push-back/cad/parts/support.SLDPRT
74.6 x 85.5 x 3.00 mm

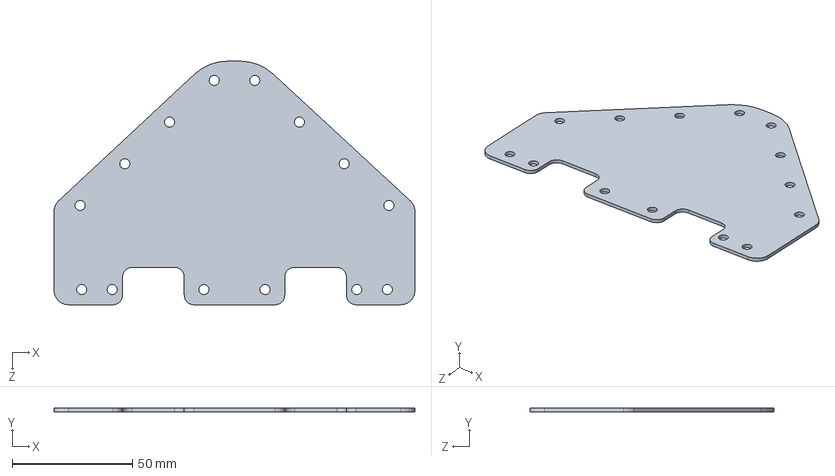
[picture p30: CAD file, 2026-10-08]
seasons/2025-26-push-back/cad/parts/对位板3.SLDPRT
150.0 x 1.50 x 101.2 mm

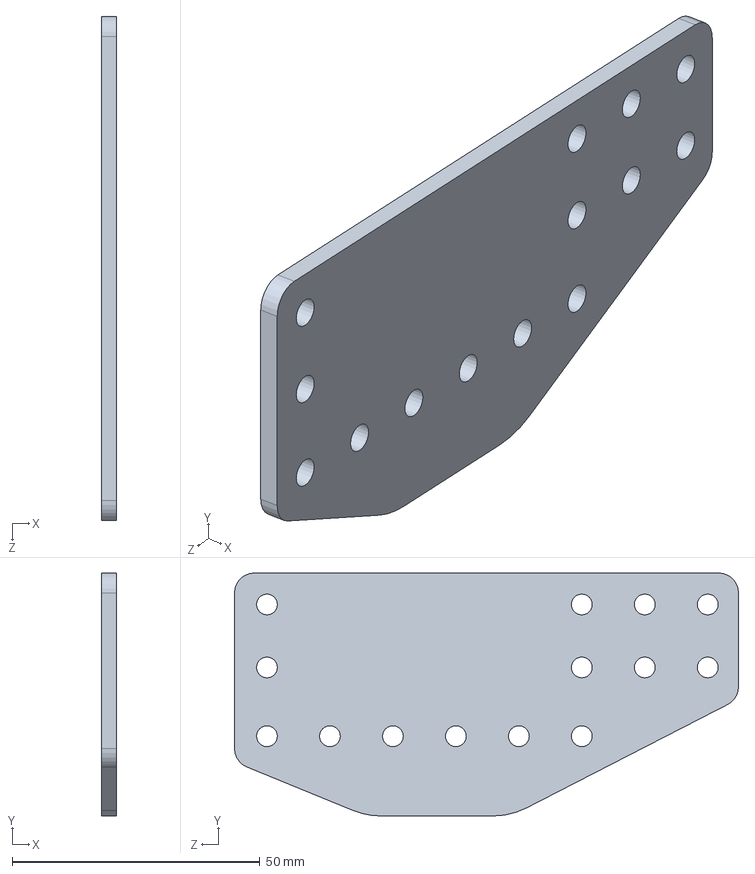
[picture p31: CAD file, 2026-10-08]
seasons/2025-26-push-back/cad/parts/sled-V2.SLDPRT
3.00 x 49.0 x 101.7 mm

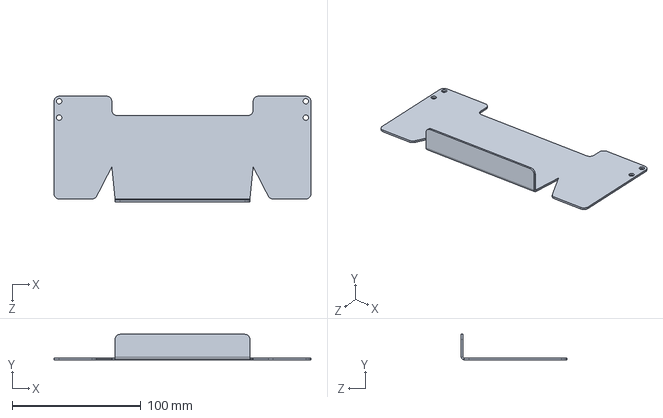
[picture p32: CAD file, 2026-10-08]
seasons/2025-26-push-back/cad/parts/de.SLDPRT
200.0 x 19.9 x 82.2 mm

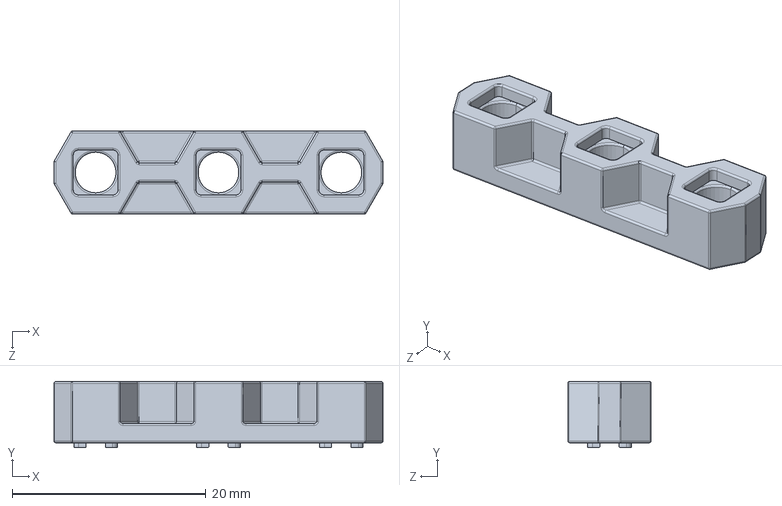
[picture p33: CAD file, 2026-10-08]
seasons/2025-26-push-back/cad/parts/窄轴承座.SLDPRT
34.0 x 6.85 x 8.60 mm

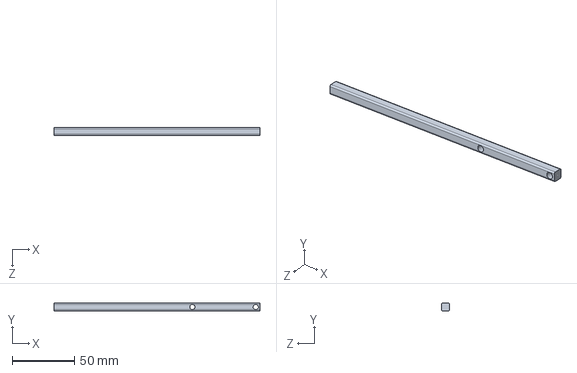
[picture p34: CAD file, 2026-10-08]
seasons/2025-26-push-back/cad/parts/侧钩粗轴.SLDPRT
165.1 x 6.32 x 6.32 mm

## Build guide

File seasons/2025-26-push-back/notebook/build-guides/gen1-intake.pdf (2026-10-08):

# 吸取搭建

1*1L 20 | 2
窄C 30 | 2
窄C 27 | 2
窄C 17 | 1
窄C 25 | 2

## 一、框架搭建

安装轴承座，安装1个

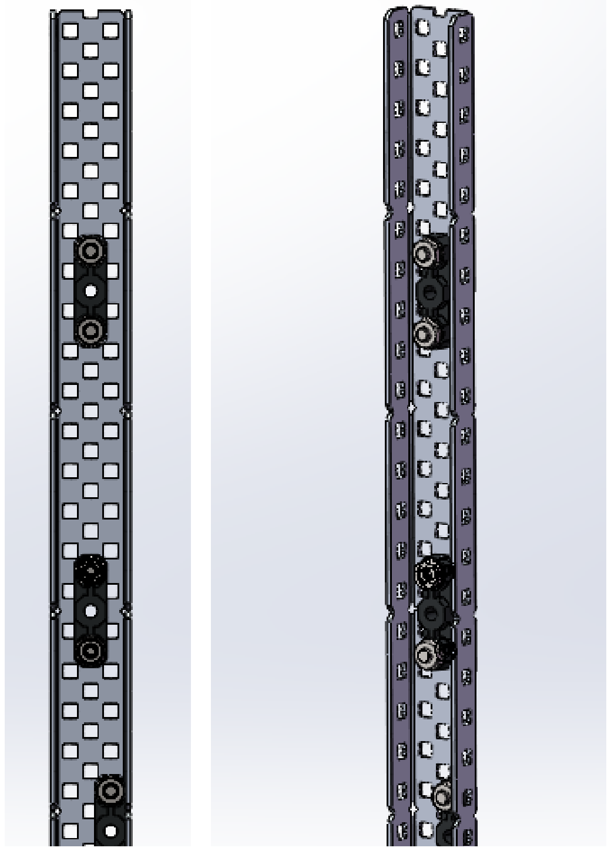
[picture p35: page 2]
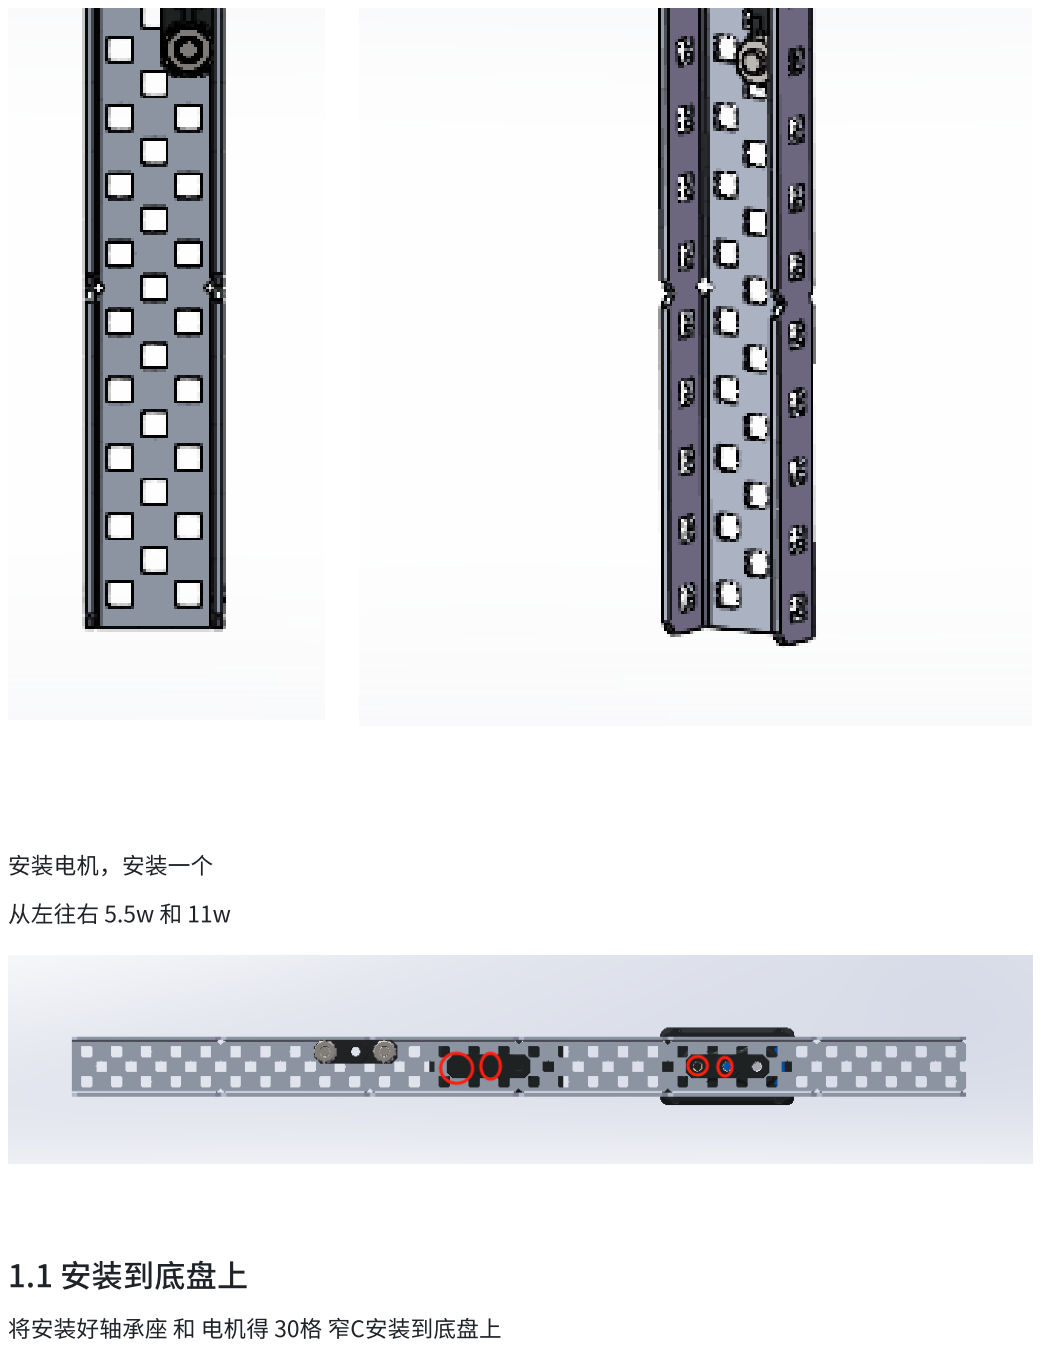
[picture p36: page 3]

安装电机，安装一个

从左往右 5.5w 和 11w

## 1.1 安装到底盘上

将安装好轴承座 和 电机得 30格 窄C安装到底盘上

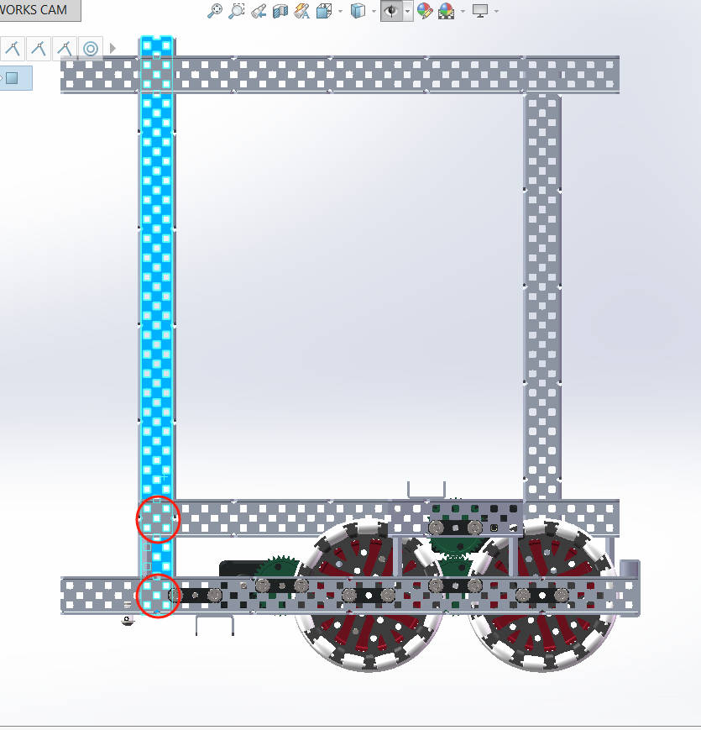
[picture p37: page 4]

安装27格窄C到底盘上

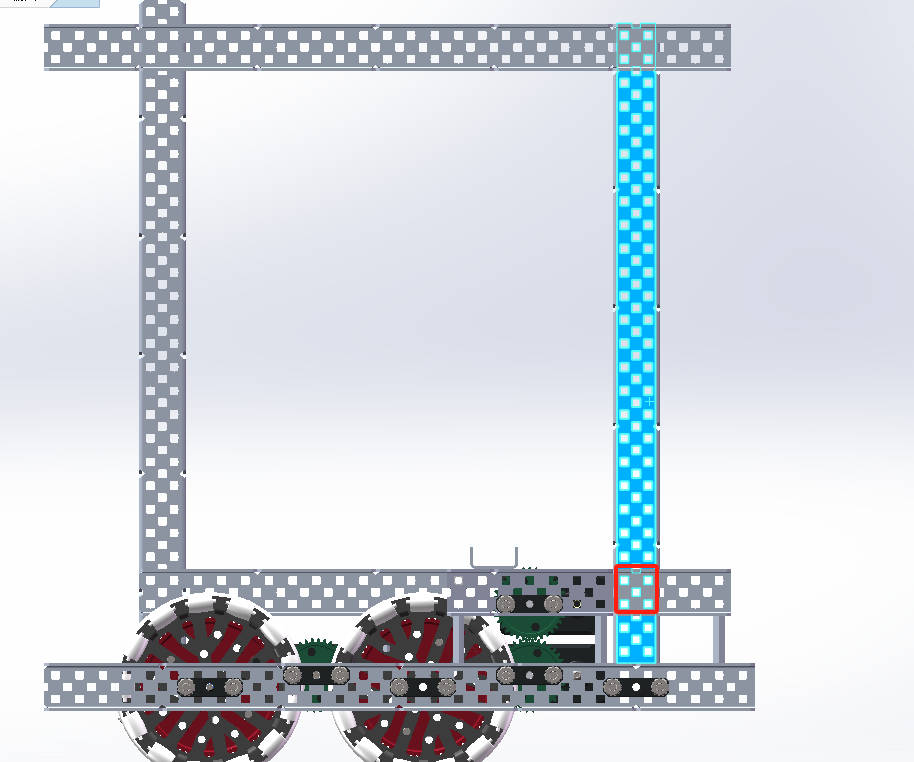
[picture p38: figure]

安装顶上29格横梁

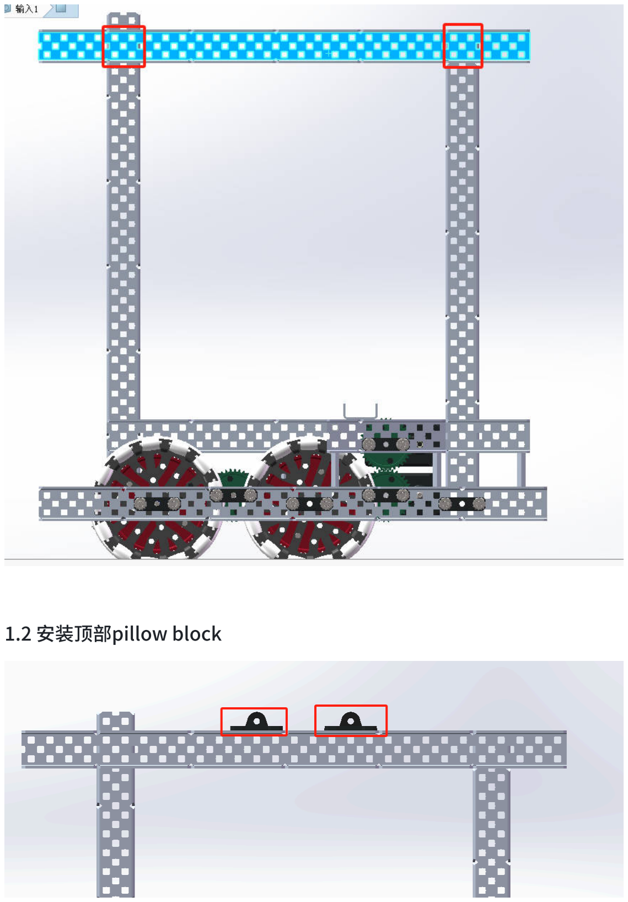
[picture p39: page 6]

## 1.2 安装顶部pillow block

## 1.3 安装1*1L

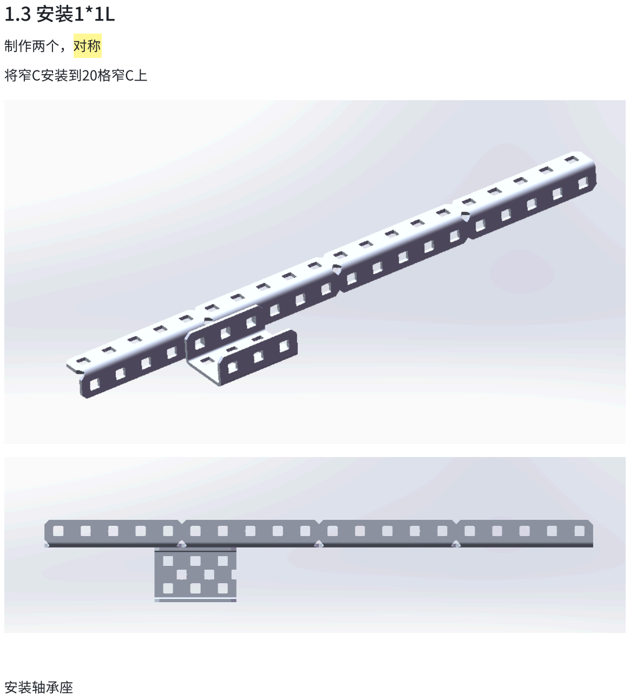
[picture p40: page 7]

制作两个，对称

将窄C安装到20格窄C上

安装轴承座

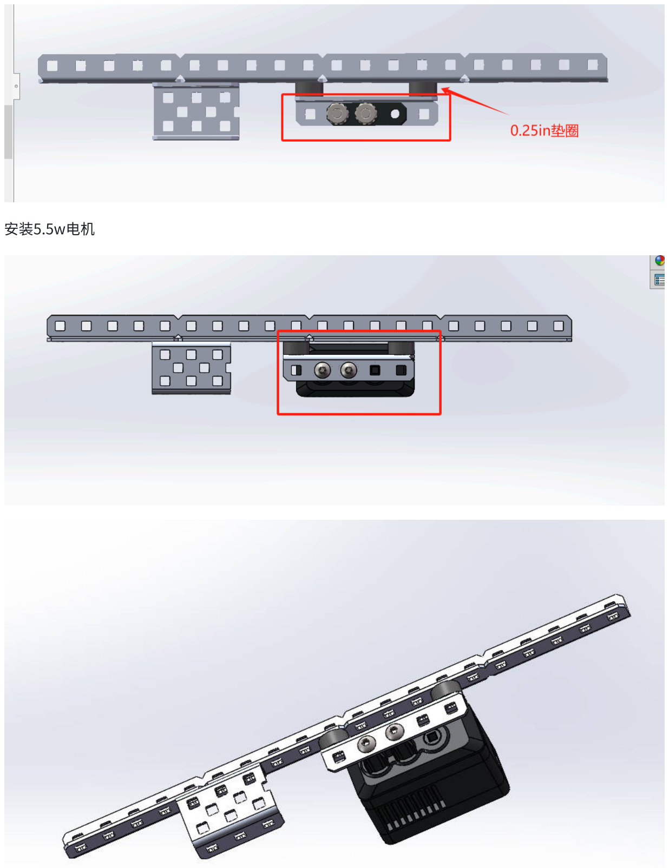
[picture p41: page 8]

安装5.5w电机

## 1.4 安装到底盘上

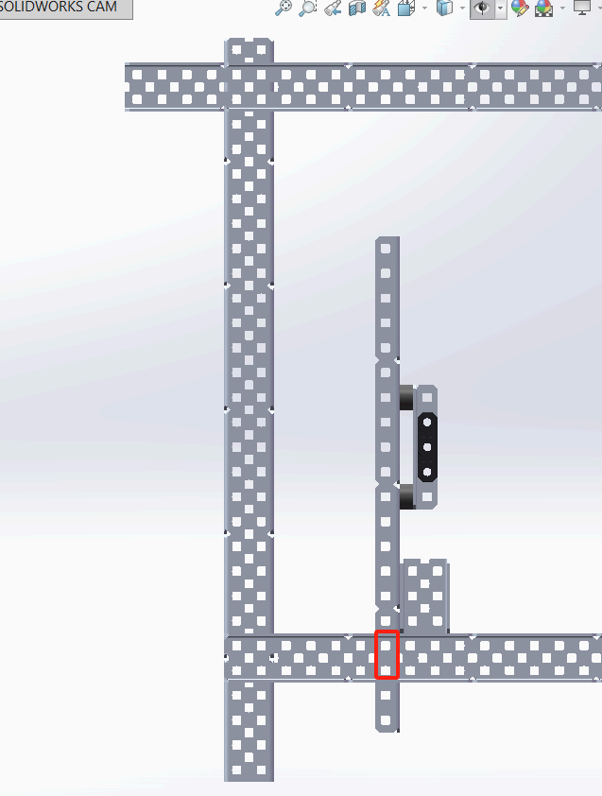
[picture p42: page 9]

另外一侧电机的对称安装即可

## 1.5 安装螺母柱支撑

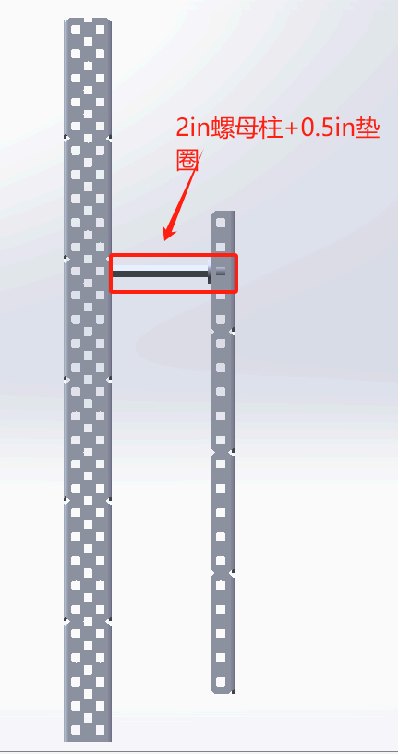
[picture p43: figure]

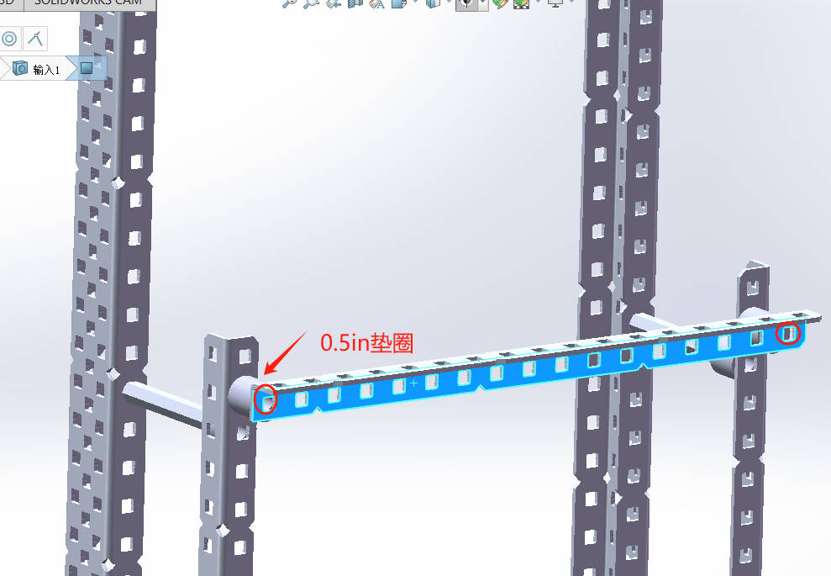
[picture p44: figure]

## 1.6 安装4孔窄C

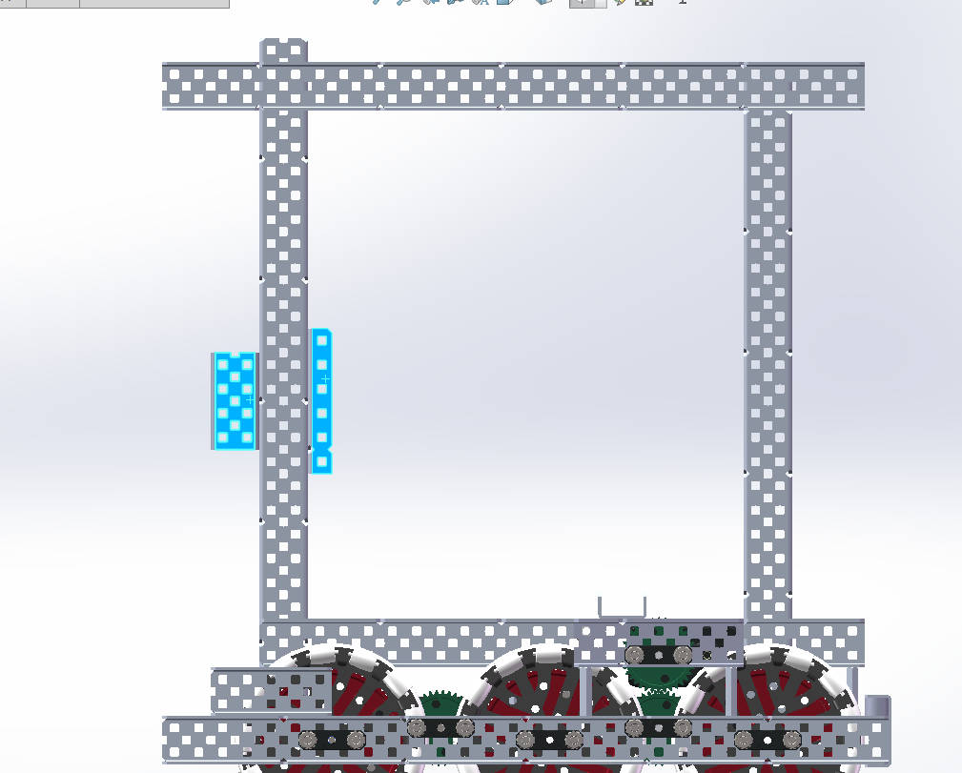
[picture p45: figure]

## 1.7 安装第一层吸取

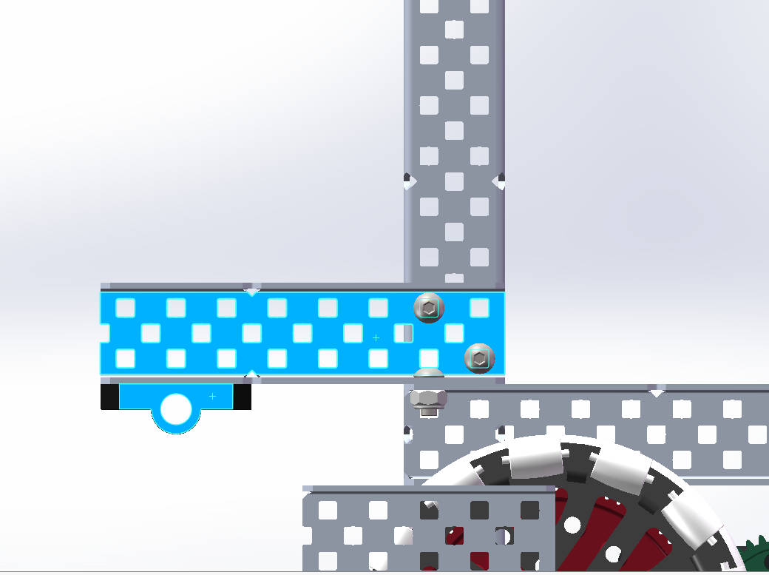
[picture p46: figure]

## 二、安装滚筒

## 准备传动轴

长度 | 数量
30.4cm 细轴 | 3
25.4cm 细轴 | 2
26.7cm细轴 | 1
27.9cm粗轴 | 1

## 三、最后一级滚筒

安装3个轴承座

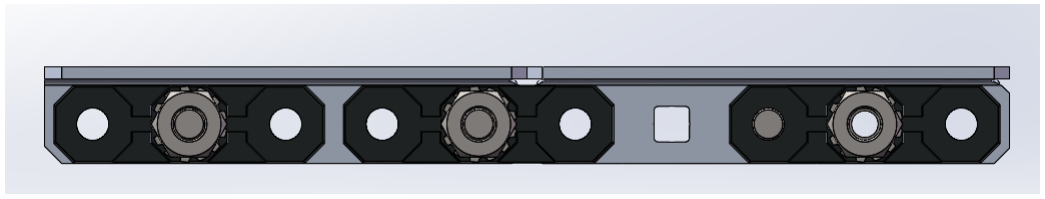
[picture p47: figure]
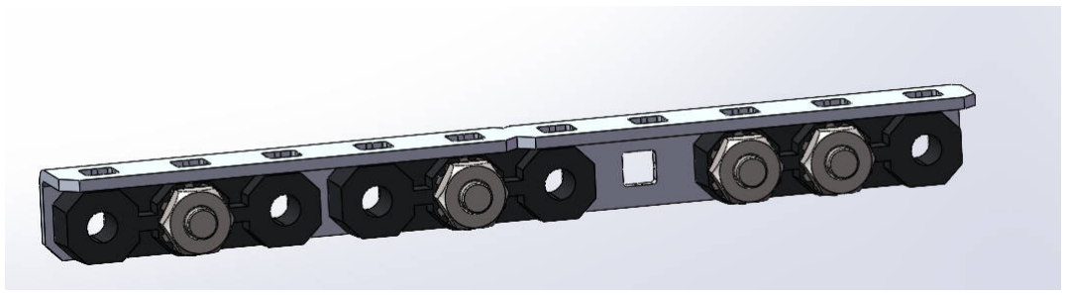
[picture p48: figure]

安装固定横梁

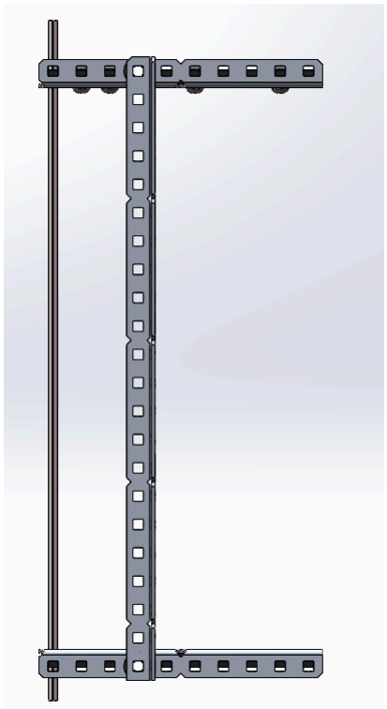
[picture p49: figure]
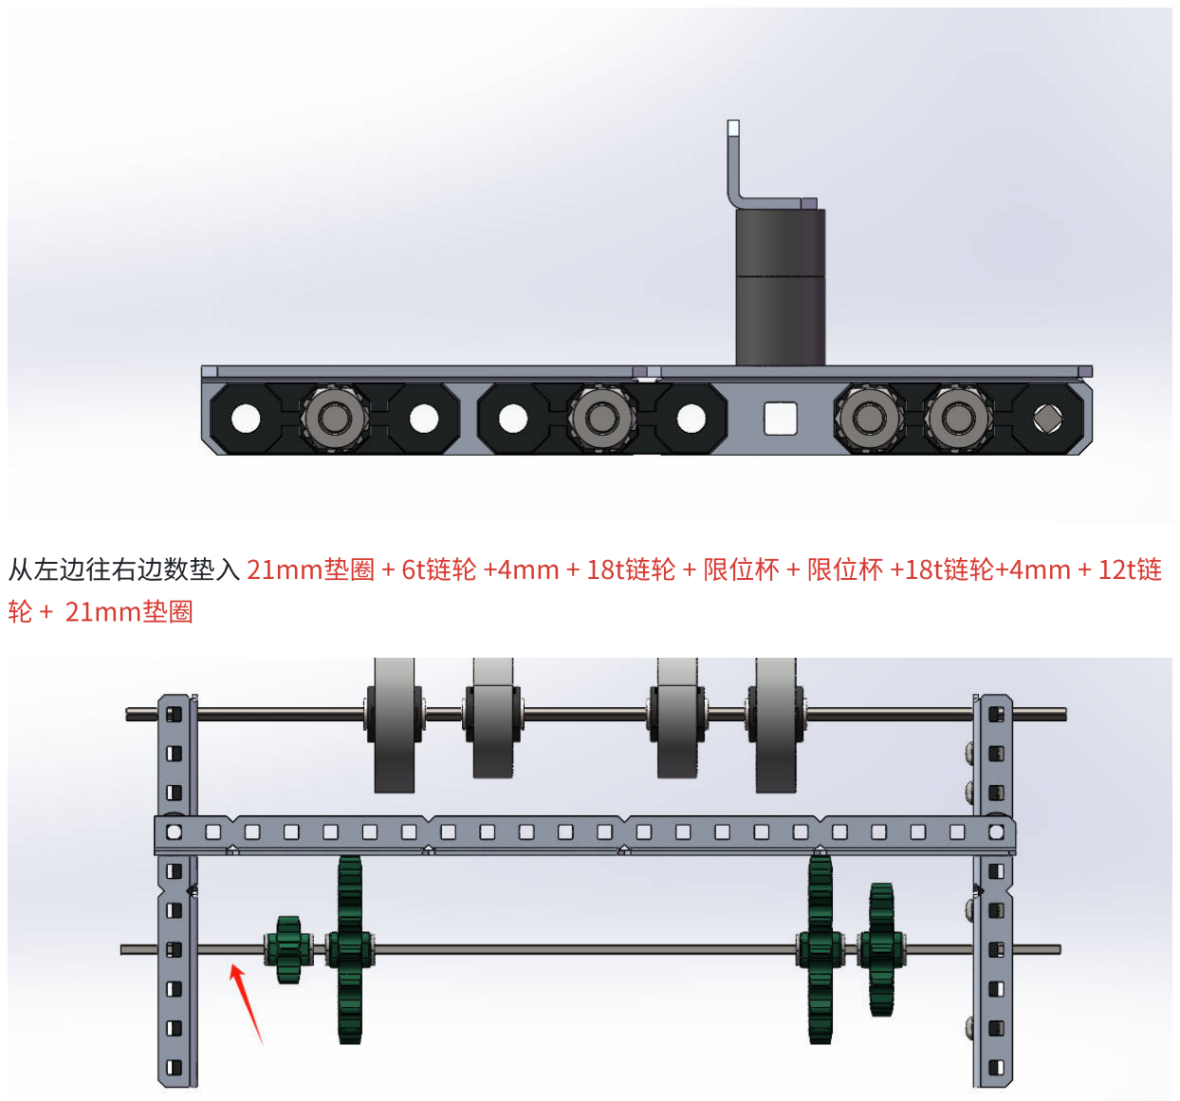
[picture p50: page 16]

从左边往右边数垫入 21mm垫圈 + 6t链轮 +4mm + 18t链轮 + 限位杯 + 限位杯 +18t链轮+4mm + 12t链 轮 + 21mm垫圈

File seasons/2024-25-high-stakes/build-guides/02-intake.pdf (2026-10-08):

## 02 intake搭建

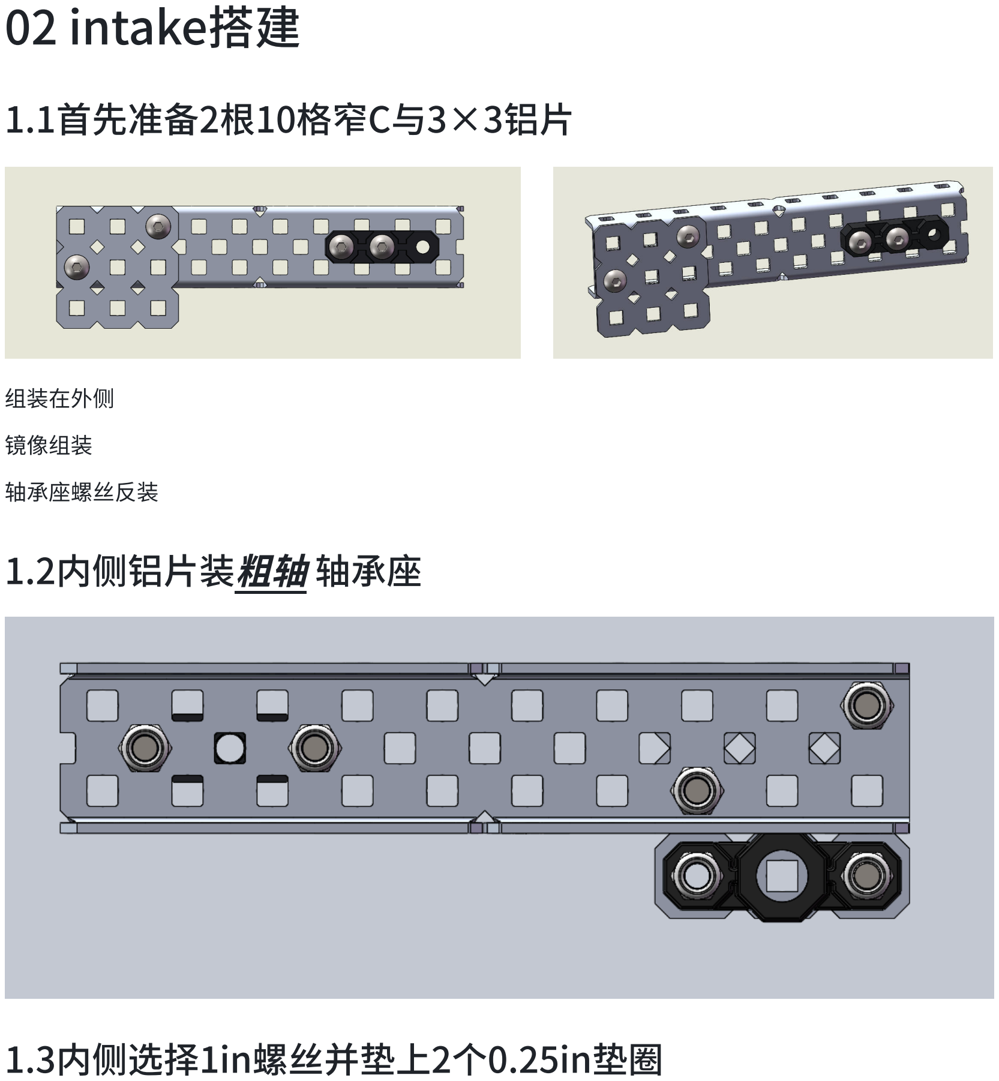
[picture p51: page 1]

1.1首先准备2根10格窄C与3×3铝片

组装在外侧

镜像组装

轴承座螺丝反装

1.2内侧铝片装粗轴 轴承座

1.3内侧选择1in螺丝并垫上2个0.25in垫圈

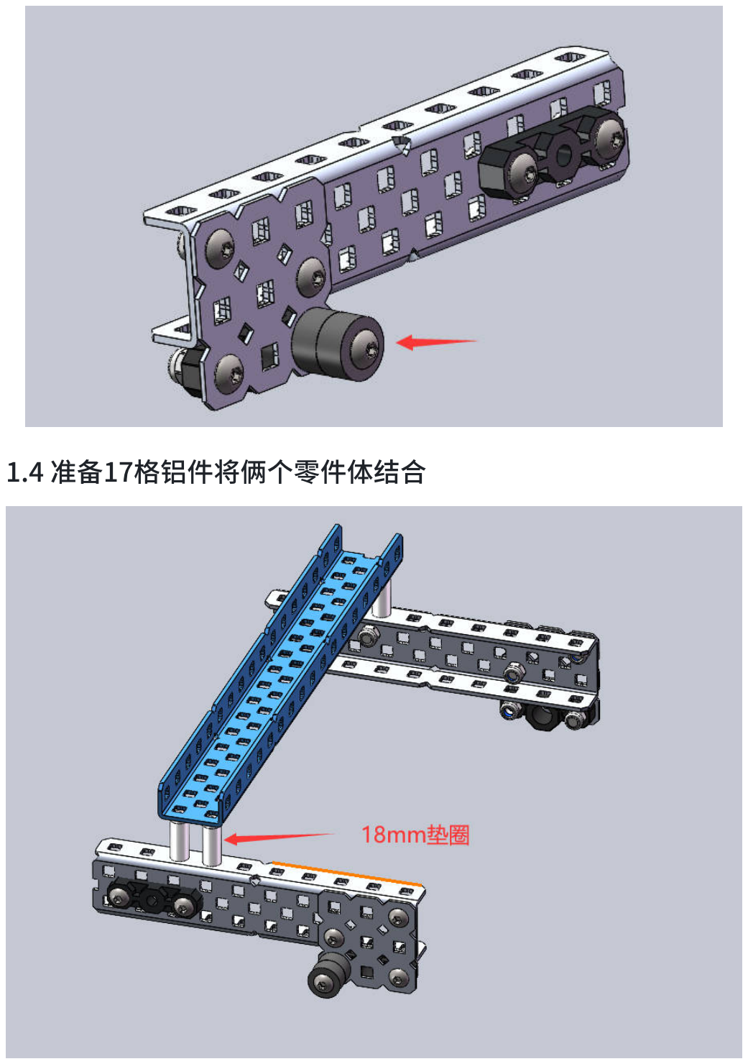
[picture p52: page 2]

1.4 准备17格铝件将俩个零件体结合

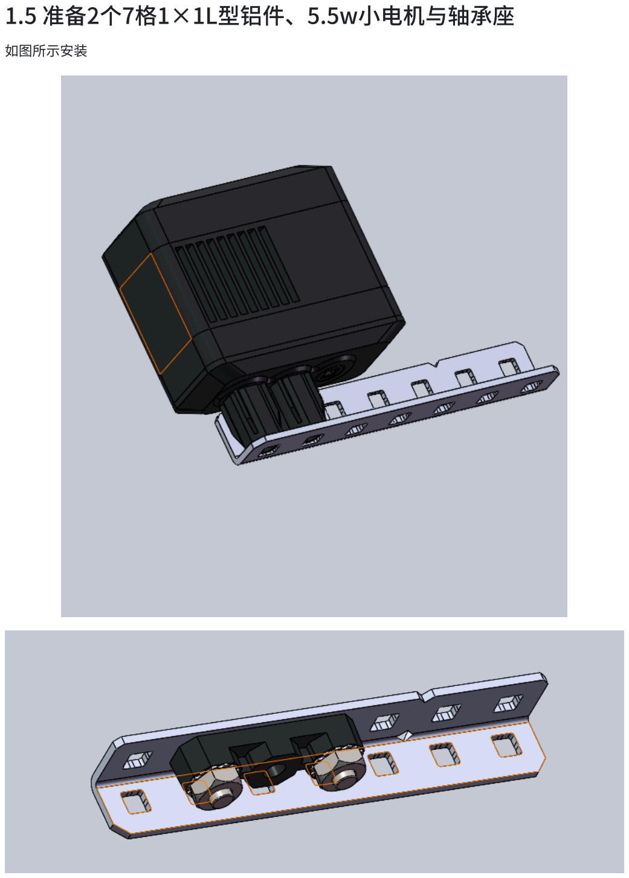
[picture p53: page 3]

1.5 准备2个7格1×1L型铝件、5.5w小电机与轴承座

如图所示安装

1.6铝件方向与位置

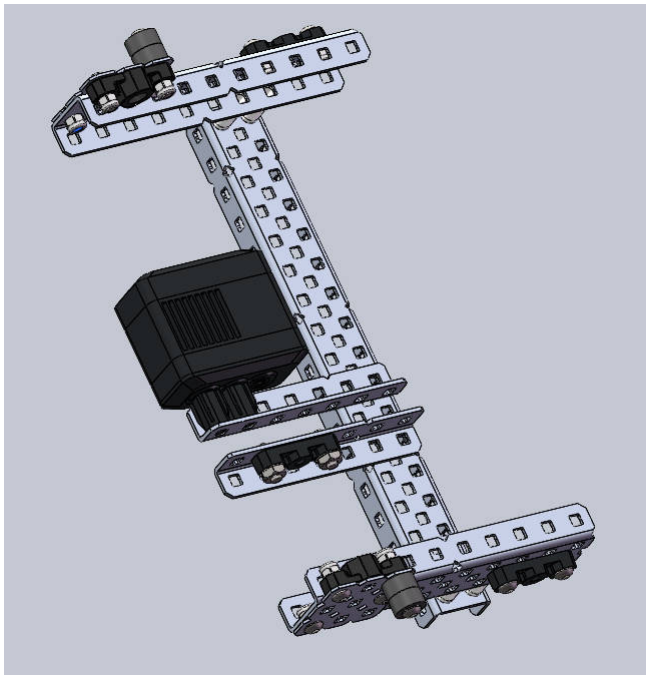
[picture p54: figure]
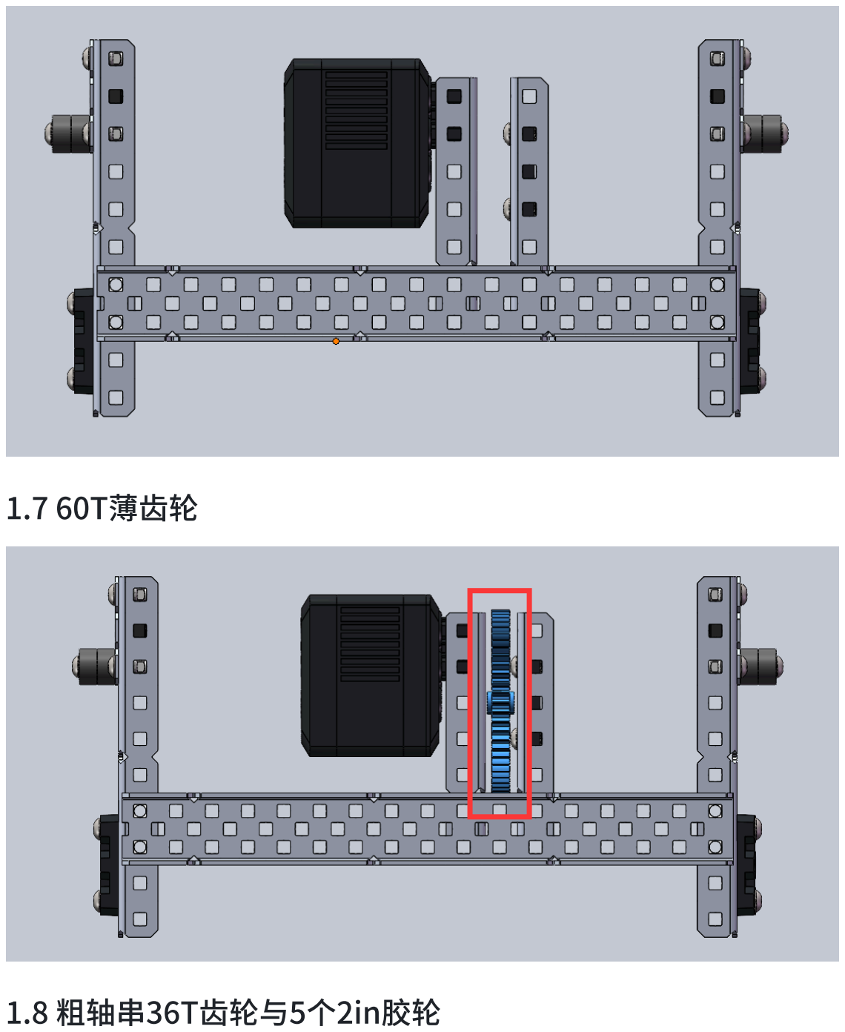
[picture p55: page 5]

1.7 60T薄齿轮

1.8 粗轴串36T齿轮与5个2in胶轮

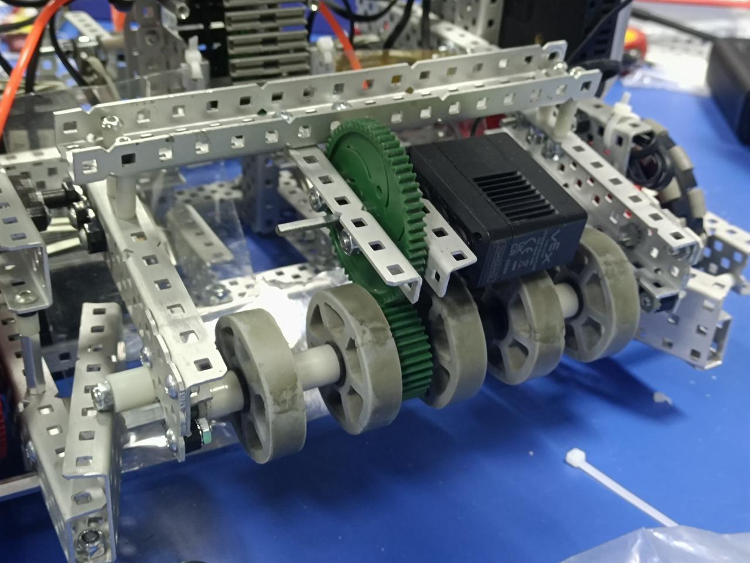
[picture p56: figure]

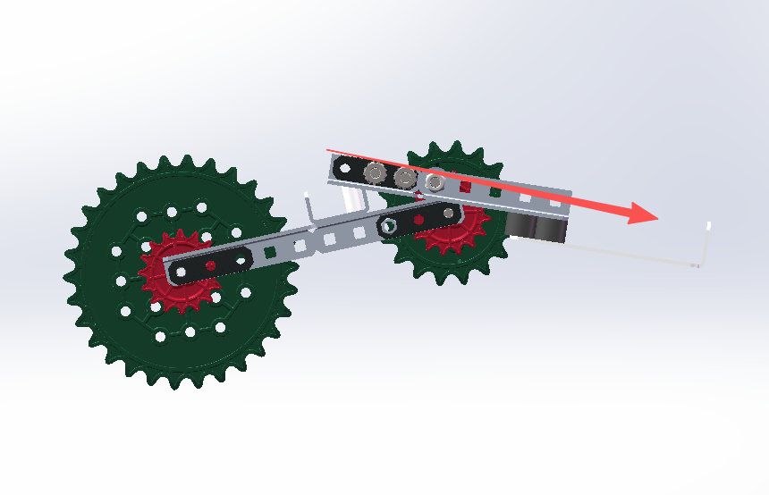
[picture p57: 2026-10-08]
seasons/2025-26-push-back/media/gen2-assembly-render.jpg

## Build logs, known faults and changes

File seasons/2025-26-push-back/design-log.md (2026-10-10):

# 2025–26 *Push Back*: design log

We built three robots this season. Each one was replaced because testing or competition showed something it could not do. This page follows that chain: the problem we saw, the options, what we chose and why, and what happened next.

**Sources.** Everything here comes from our own documents, cited by page. **IR** is the season improvement record, written by our mentor, my teammates and me ([PDF](notebook/2025-26-improvement-record.pdf)). **NB** is the engineering notebook ([PDF](notebook/2025-26-engineering-notebook.pdf)). The build guides are in [notebook/build-guides](notebook/build-guides/), and the CAD (which I built with our mentor) is in [cad/](cad/README.md).

| | Gen 1 | Gen 2 | Gen 3 ("S machine") |
|---|---|---|---|
| **Shape** | Roller-cascade intake, rubber-band rollers, 29 holes wide | Ramp robot: front intake, rear scoring, rubber-wheel intake, double-row storage, belt-and-paddle transfer, 27 holes wide | Single S-shaped storage channel, rollers at different speeds, PC centring plate |
| **Fate** | Replaced: too little storage, rollers tangled | Its design won WRCT 2025 for our sister team 117B; replaced because it leaked blocks and jammed | Division 2 champion and runner-up at Suzhou, Nov 2025 |
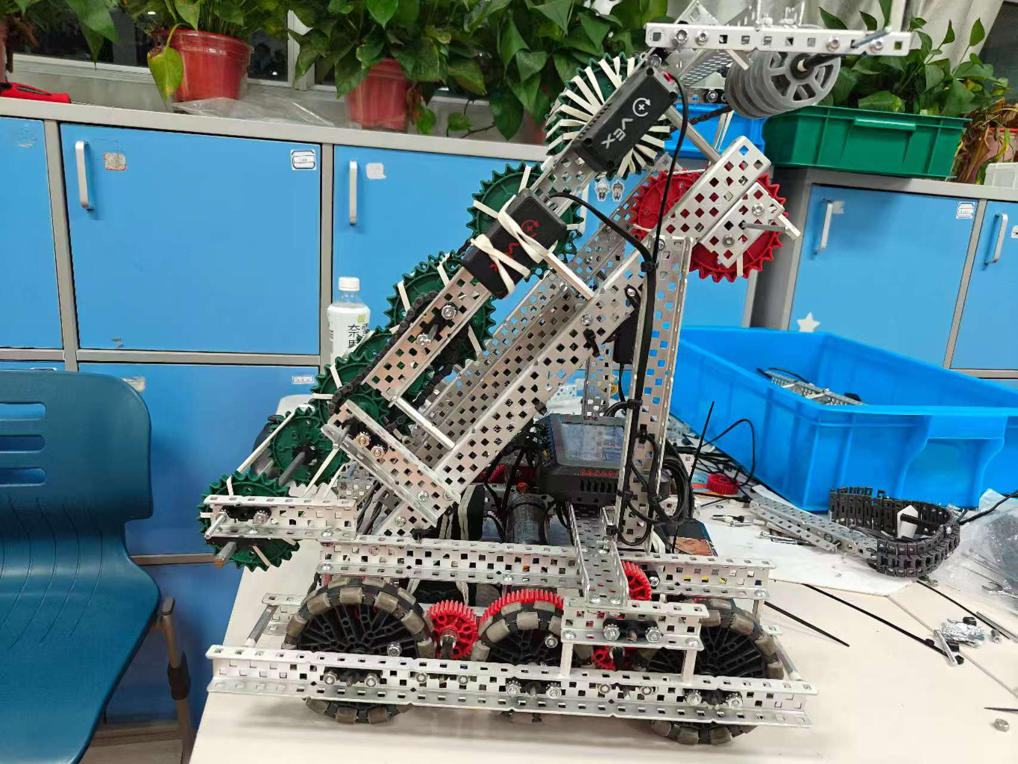
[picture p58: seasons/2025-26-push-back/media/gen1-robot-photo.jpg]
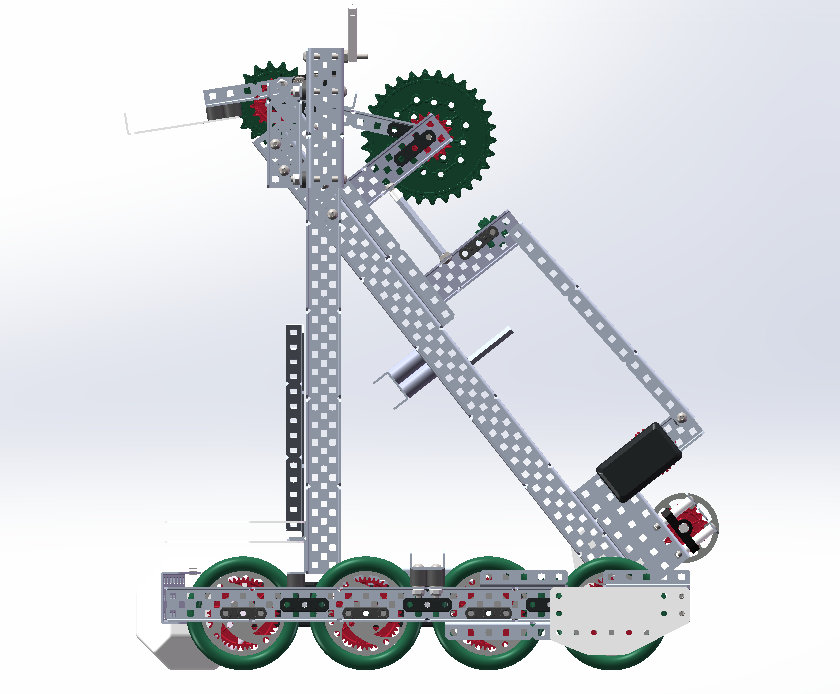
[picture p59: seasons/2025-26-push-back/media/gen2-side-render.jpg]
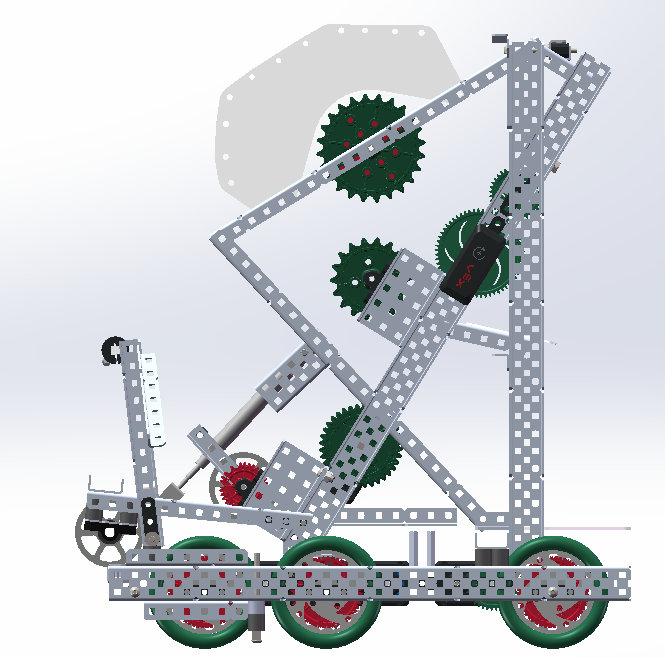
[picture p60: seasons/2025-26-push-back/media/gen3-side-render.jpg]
| |  |  |  |

---

## How we started: choosing a robot type

Before building, the notebook compared three robot types (NB p.8–9):

| Type | For | Against |
|---|---|---|
| Lift robot | Simple, low centre of gravity, drives under the long goal | Unstable while scoring, stores few blocks, drops them from the back |
| "Big stomach" | Stores the most blocks, stable, strong in contact | Heavy and slow, wide enough to get stuck between goals |
| **Ramp robot** | **Agile, enough storage, front intake / rear scoring suits loader → long goal** | Weaker grip on blocks, less pushing power |

**We chose the ramp robot:** it had no major weakness and balanced storage against agility. A concept study ([PDF](notebook/2025-26-concept-study.pdf)) had already worked through the motor budget. The V5 rules cap total motor power at 88 W, which allows only a few mixes of 11 W and 5.5 W motors. The notebook set a rule we kept all season: give one motor several jobs where possible, and never add a motor just to use up the 88 W (NB p.5–6).

---

## Chapter 1. Gen 1 → Gen 2

The team meeting that opened Gen 2 (IR p.1) started from two failures of Gen 1: **it could not store enough blocks**, and **its rubber-band rollers tangled with other robots**. We also wanted a way to knock opponents' blocks out of goals.

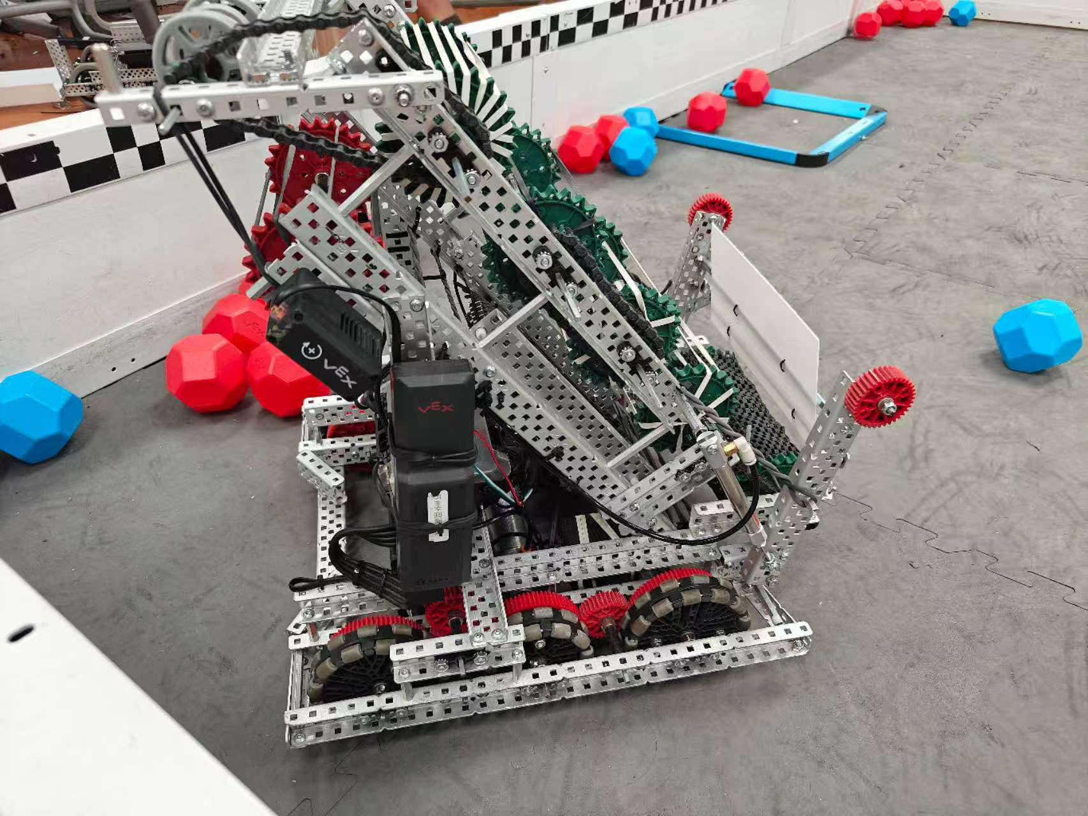
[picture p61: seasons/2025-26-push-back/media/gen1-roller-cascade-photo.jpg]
Gen 1


| Subsystem | Problem | Options | Decision and reason | Evidence |
|---|---|---|---|---|
| **Drive ratio** | | | **36:48** gearing on 3.25 in omni wheels with 600 rpm motors: 450 rpm at the wheel, about 76.6 in/s (1.95 m/s) free speed | IR p.2; `main.cpp` chassis set-up |
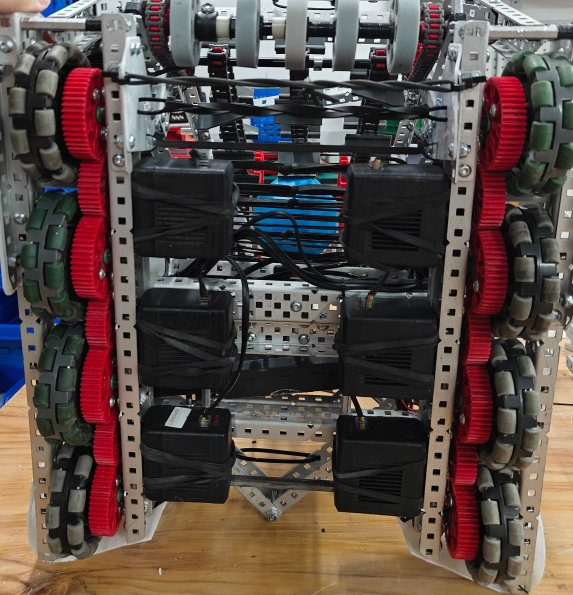
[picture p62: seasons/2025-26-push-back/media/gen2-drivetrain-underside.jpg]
| **Wheels per side** | Must cross the barrier and park without getting stuck | 2, 3 or 4 wheels | **4**: the turning centre sits closer to the middle of the robot, it crosses the barrier more easily, and it doesn't snag in the park zone | IR p.2–3 ·  |
| **Chassis size** | Gen 1 was 29 holes wide; parking alone was very tight | 29 vs 27 wide | **30 × 27 holes.** At 27, parking became easy | IR p.2; [Gen 1](notebook/build-guides/gen1-chassis.pdf) and [Gen 2](notebook/build-guides/gen2-chassis.pdf) chassis guides |
| **Intake surface** | Rubber bands tangled with other robots in contact and were pulled off the rollers | Bands vs wheels | **Rubber wheels** | IR p.3; NB p.15 |
| **Intake wheel size** | | 1.625 in vs 2 in, both tested | **2 in**: it picked blocks up better, because the larger radius grips more | IR p.3 |
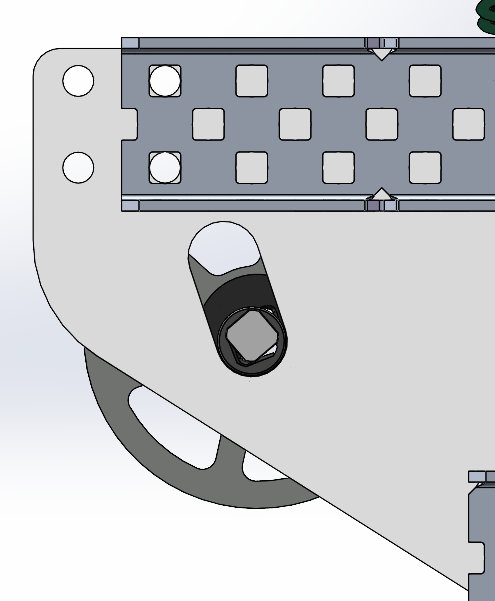
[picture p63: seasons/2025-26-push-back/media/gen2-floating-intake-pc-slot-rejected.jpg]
| **Intake mounting** | Stiff wheels against hard blocks jammed when the intake was fixed | A sliding slot cut in a PC plate, or a rail built from bearing blocks | **Floating intake on a bearing-block rail.** The PC slot was dropped because the season allowed only 12 PC plates and we needed them elsewhere | IR p.4 ·  |
| **Storage** | Gen 1 stored too few blocks | | **Double-row storage** | IR p.5 |
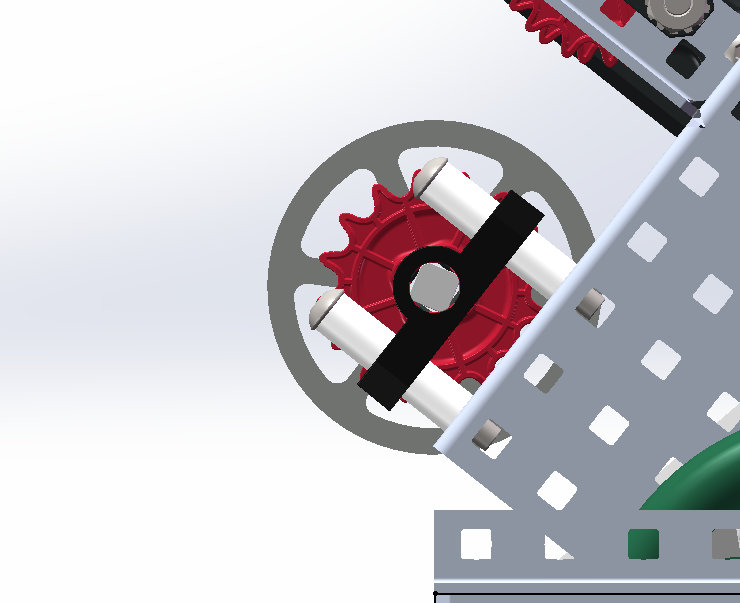
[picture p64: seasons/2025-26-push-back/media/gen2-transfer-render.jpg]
| **Transfer** | Blocks were passed up one roller at a time; the gearing was complicated and the band rollers dragged on each other | | **Belt with paddles**, which puts less pressure on the blocks | IR p.6 ·  |
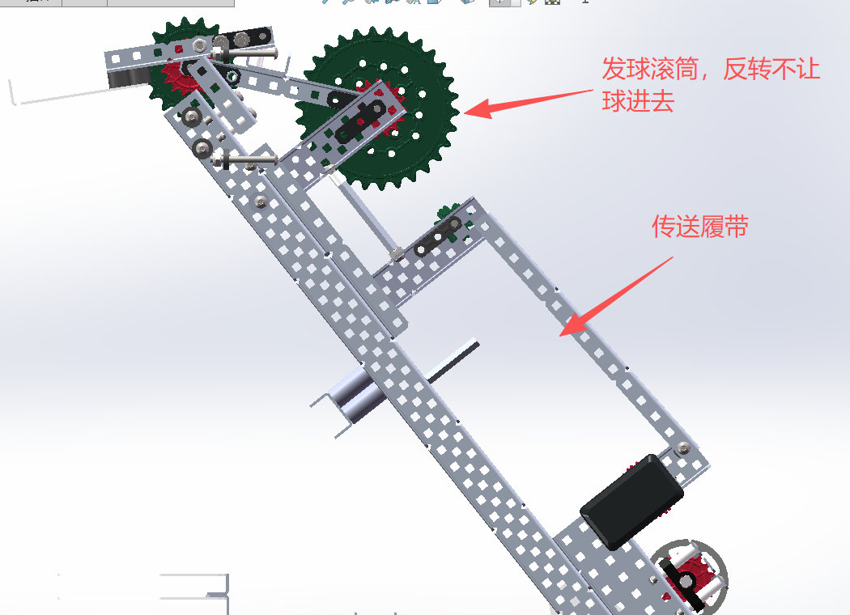
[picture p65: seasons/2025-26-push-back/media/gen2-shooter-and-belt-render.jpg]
| **Shooter** | | | A **30T and an 18T sprocket** squeeze each block out; running the roller backwards stops blocks entering | IR p.7–8 ·  |

### The descorer: four tries

Knocking opponents' blocks out of a goal took four changes (IR p.9–12):
1. **The idea:** hit the blocks with a flat face, using the robot's own acceleration.
2. **Too heavy:** the aluminium version weighed too much, so it became a **bent polycarbonate (PC) plate**. The build guide specifies the bends: 90° at 30 mm, 30° at 15 mm ([guide](notebook/build-guides/gen2-middle-goal-plate.pdf)).
3. **Didn't fit:** the plate was **cut back to match the goal's notch**.
4. **Wrong angle:** hitting flat and hitting at an angle gave different results, so we added a mount that holds the plate **at an angle**.

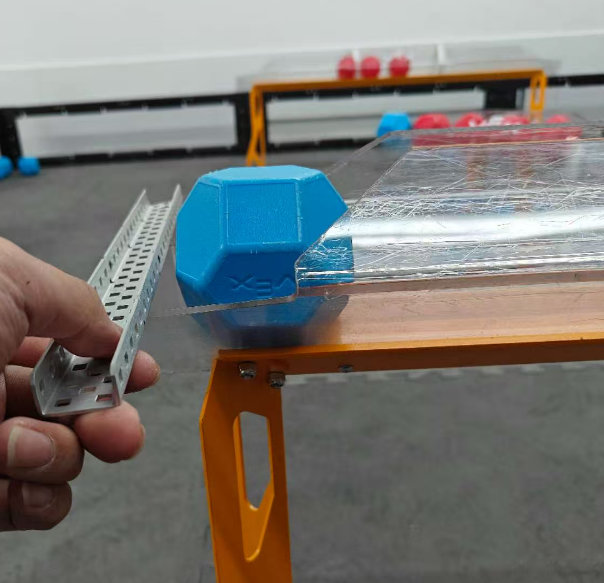
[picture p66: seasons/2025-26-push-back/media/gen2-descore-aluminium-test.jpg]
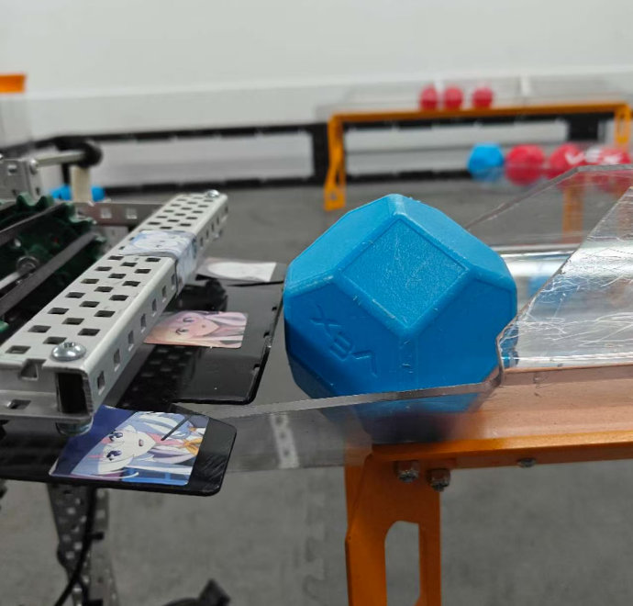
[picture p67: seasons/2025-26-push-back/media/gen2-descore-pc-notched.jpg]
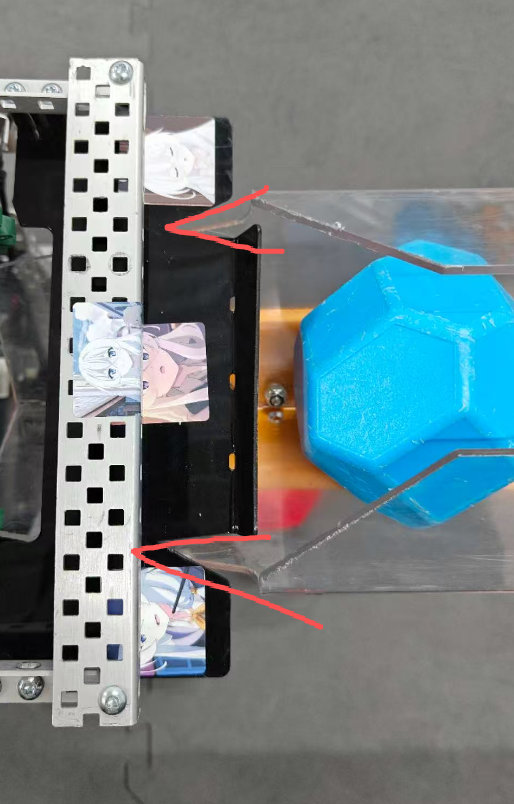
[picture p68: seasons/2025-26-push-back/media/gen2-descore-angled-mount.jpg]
|  |  |  |
|---|---|---|
| Aluminium test | Bent PC, notched | Angled mount |

Gen 2 in the pits at the Huzhou invitational, August 2025

*Gen 2 in the pits at the Huzhou invitational, August 2025: the ramp with its belt and paddles.*

---

## Chapter 2. Learning from a win

On **16 August 2025** our club's sister team **117B** took a robot of the Gen 2 design to the **WRCT 2025 selection** (World Robot Contest Tournament trials) and won the high-school division (IR p.14). While we were upgrading our own robot to Gen 2, I helped 117B during development, in the pits and with their code.

WRCT 2025 selection

*117B at the WRCT 2025 selection.*

Winning didn't make the design right. Watching it compete showed us what Gen 2 could not do (IR p.15):
1. **Blocks leaked at the middle goal.** The double-row channel let blocks fall out when scoring low.
2. **The autonomous had no edge.** The 1 + 6 route could not take both goals.
3. **Blocks jammed side by side** while scoring.

At the next team meeting we decided to design a third robot, with two goals: **a single storage channel**, and **the ability to double-park** (IR p.15).

The idea came from watching **team 16610A** at the Mall of America event. Their robot used pistons to lift itself for a double park and stored blocks in a single channel (IR p.15). Gen 3 borrows that idea; the original design is theirs.

---

## Chapter 3. Gen 3

Gen 3 in SolidWorks

*The Gen 3 assembly in SolidWorks (file `V2-RG`), which I built with our mentor. The feature tree on the left lists its subassemblies, such as `450` and `3.25-48`.*

### Motor budget: 9 motors, exactly 88 W

| Job | Motors |
|---|---|
| Drive | 6 × 11 W, 600 rpm |
| Intake | 1 × 11 W, 600 rpm |
| Feeder | 1 × 5.5 W, 200 rpm |
| Shooter | 1 × 5.5 W, 200 rpm |
| **Total** | **9 motors, 6×11 + 11 + 5.5 + 5.5 = 88 W** |

(IR p.16)

### One channel, the same capacity: the S-path

A single channel would normally hold fewer blocks than two rows. To keep Gen 2's capacity, the storage path changed **from a straight ramp to an S shape** (IR p.17).

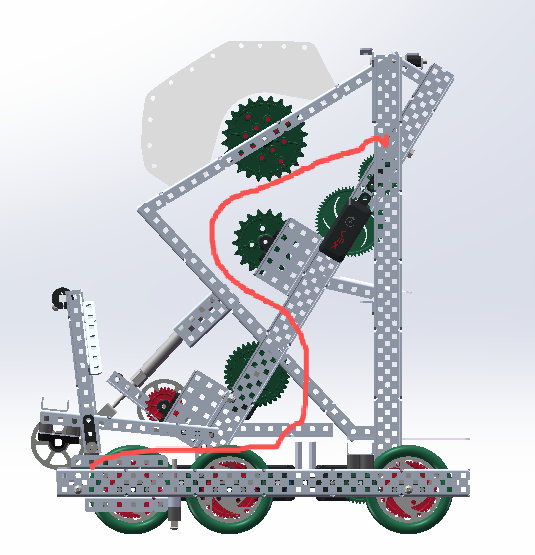
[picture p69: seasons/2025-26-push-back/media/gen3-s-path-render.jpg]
|  |  |
|---|---|
| Gen 3 in SolidWorks | The S-shaped path |

### Rollers at 20 %, 30 % and 80 %

The first test of the new intake failed: with all three roller motors at 100 %, blocks shot straight through and the robot could not hold them (IR p.18). The fix was to run the three rollers at **different speeds, 20 %, 30 % and 80 %**. That way blocks bunch up in the channel instead of passing through, and more of them fit (IR p.19–20).

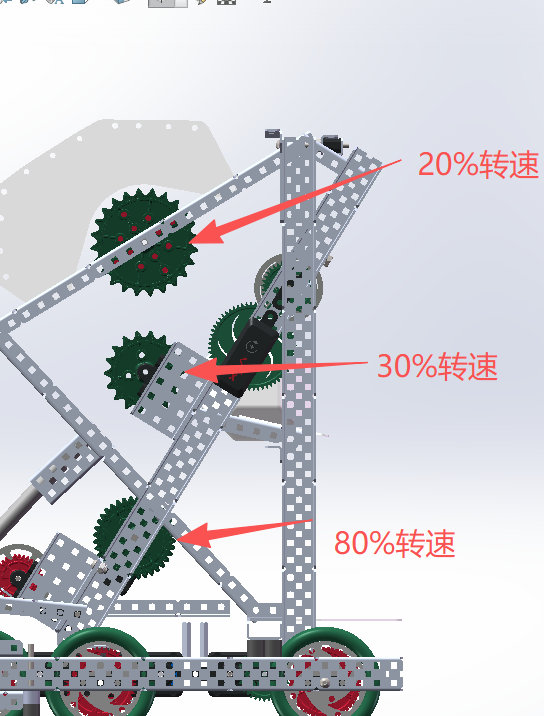
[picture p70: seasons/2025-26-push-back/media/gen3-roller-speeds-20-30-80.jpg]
Roller speeds


The autonomous code shows the result: the `lanyou` routine collects three blocks from the field and three more from a loader before scoring anything, so **six blocks are on board at once**.

### Lining up: aluminium triangle → PC centring plate

To help our driver line up quickly, we put a triangle on the back of the robot that slots into the goal's notch (IR p.20). The aluminium version centred badly, so we **drew a PC plate in CAD, shaped from the goal's own triangle** (IR p.21). I modelled it with our mentor; it is the part `对位板3` ("centring plate 3") in [cad/](cad/README.md).

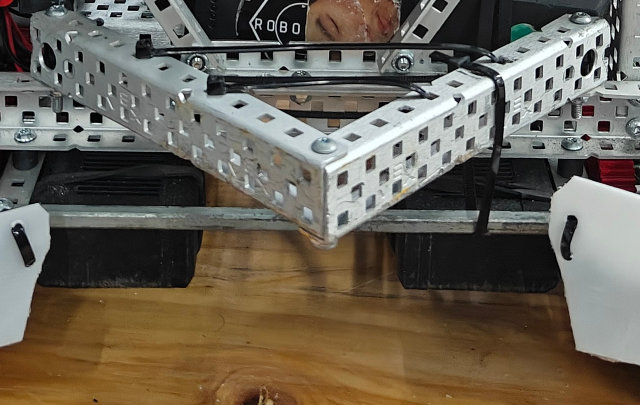
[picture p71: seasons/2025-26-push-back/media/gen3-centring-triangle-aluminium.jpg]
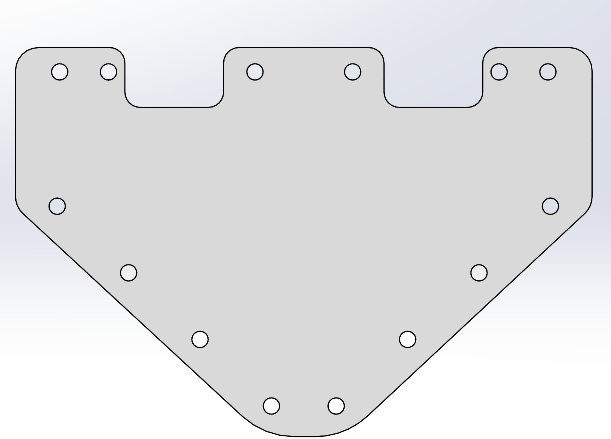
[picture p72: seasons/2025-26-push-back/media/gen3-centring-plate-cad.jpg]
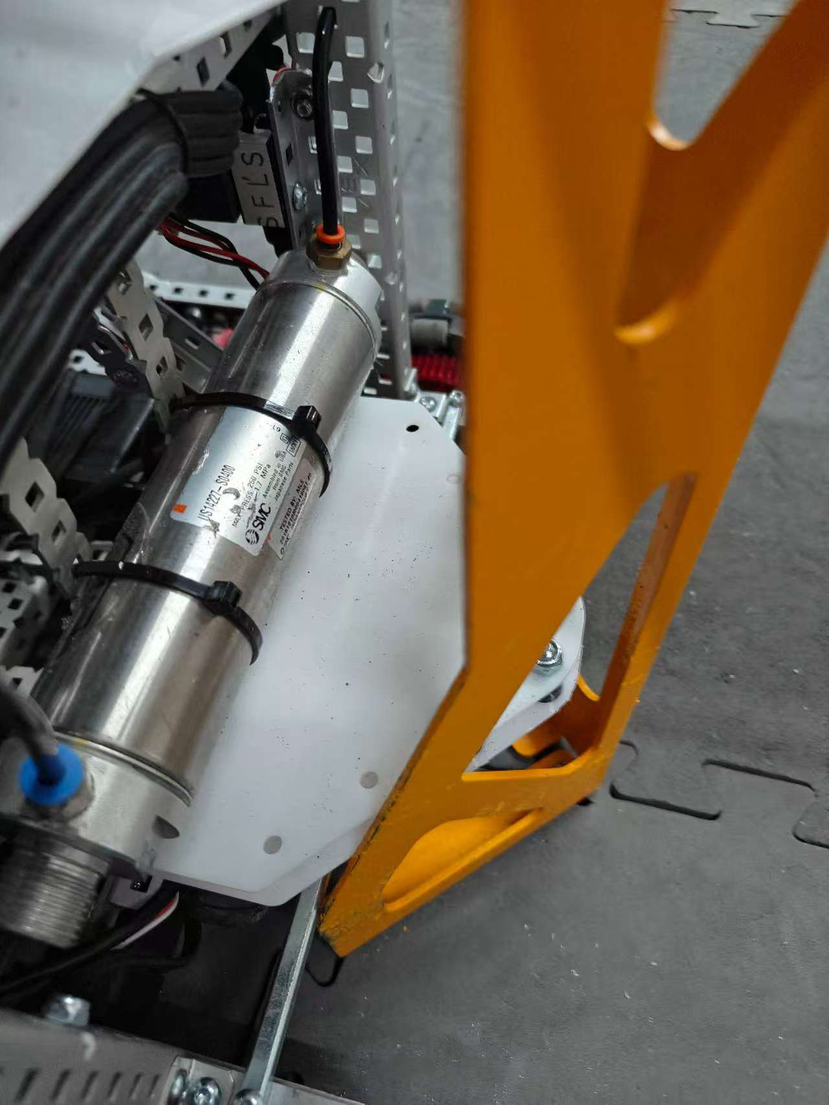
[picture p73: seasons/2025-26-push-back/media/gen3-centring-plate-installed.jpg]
|  |  |  |
|---|---|---|
| Aluminium triangle | The plate in CAD | The plate on the robot |

### Before every match

The improvement record ends with a pre-match checklist for Gen 3 (IR p.21–22): every piston linked to its stop, the scoring-wheel bands in place, the first-stage guide standoffs not bent, the loader PC plate not cracked.

---

## Smaller fixes along the way

From the notebook's problem-and-fix pages (NB p.10–16):

| Problem | Fix |
|---|---|
| Missed blocks at the long goal when the robot wasn't lined up | A PVC plate plus an aluminium guide that self-centres the robot as it drives in |
| Blocks entering the belt two at a time and jamming on a gear | Two PVC plates that funnel blocks into single file; a short reverse clears the rare jam |
| Blocks stopping on the smooth loader plate | A zip tie on the plate, so a falling block hits it and rolls into the intake |
| Chain damaged in contact | Chain moved inside the frame, behind a protective crossbeam |
| The top roller too soft to push blocks into the middle goal | Extra rubber bands on the top roller |

---

*More photos of the 2025–26 robots: [media.md](../../media.md).*

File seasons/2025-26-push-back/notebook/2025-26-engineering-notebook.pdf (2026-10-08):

E i

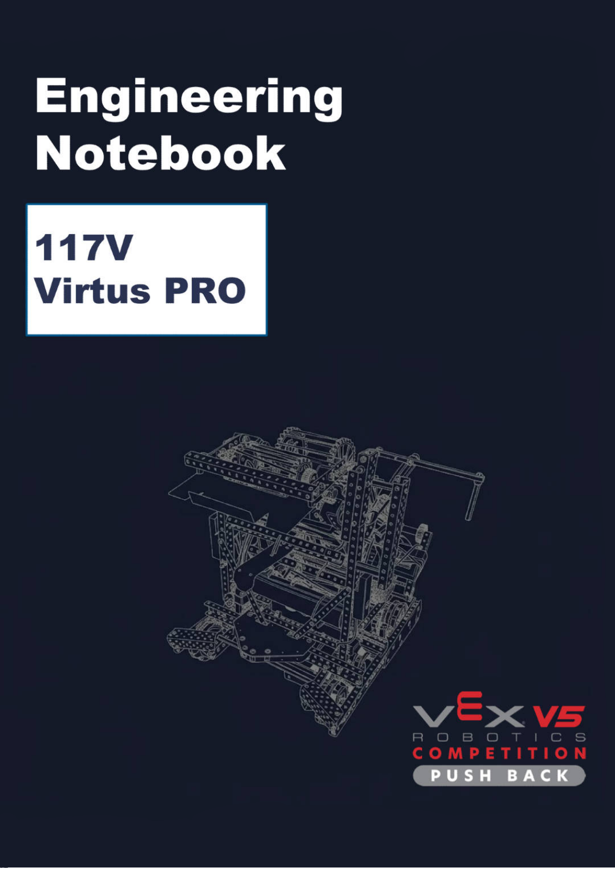
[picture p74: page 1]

e

1-

## it Tstsnttstsntsottttsttsanot

## 参赛队员

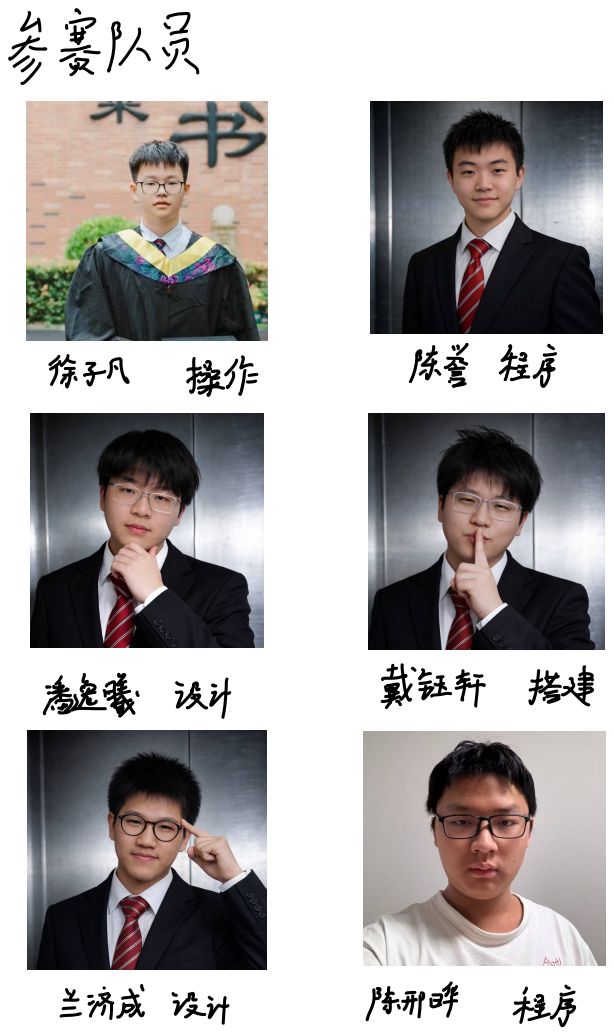
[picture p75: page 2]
徐子凡; 潘逸曦 设计; 戴钰轩 搭建; 兰济成 设计; 陈邢晔

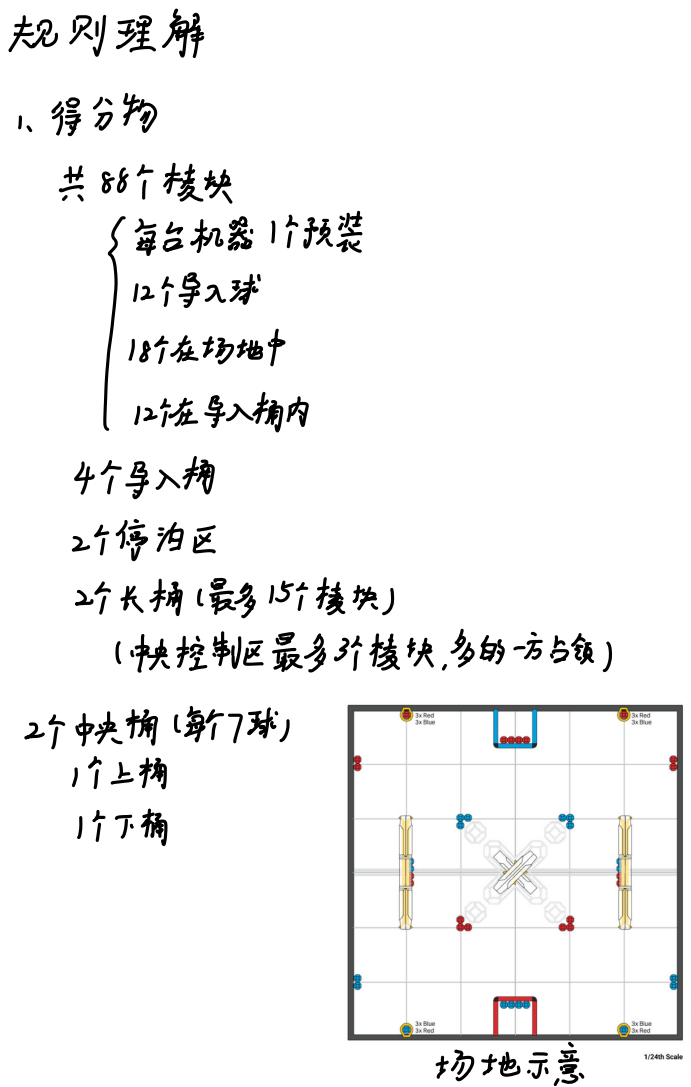
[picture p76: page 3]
1 得分物; 每台机器 1个预装; 12个导入球; 18个在 场地中; 12个在导入桶内 4个导入桶; 2个停泊区; 2个长桶 最多 15个棱块; 1中央控制区最多3个棱块 多的一; 方占领; 2个中央桶 每个7球; 1个上桶; 1个下桶

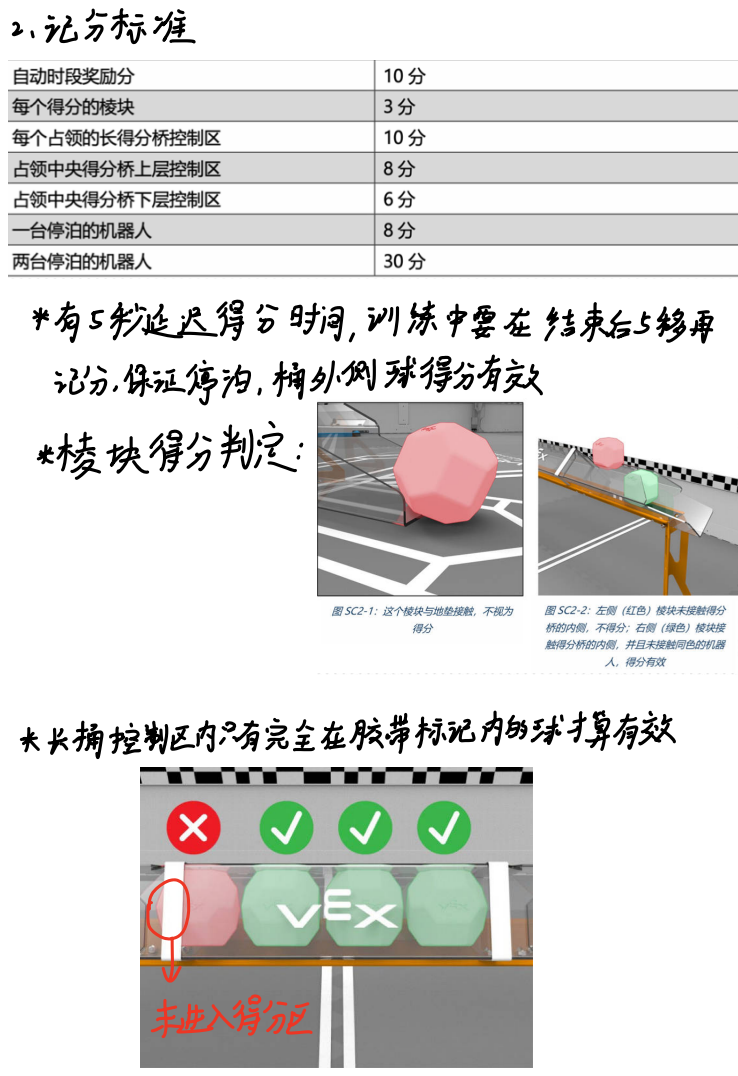
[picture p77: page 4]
棱 块得分判定; 长长桶控制区内只有完全在胶带标记内的球才算有效; 未进入得分区

有 5秒延迟得分时间 训练中要在 结束后5移再
记分 保证停泊 桶外侧 球得分有效

停泊得分 只要车不接触停泊区外地垫就有效

可以靠把车卡在停泊区结构的塑料上尝
试 双停泊

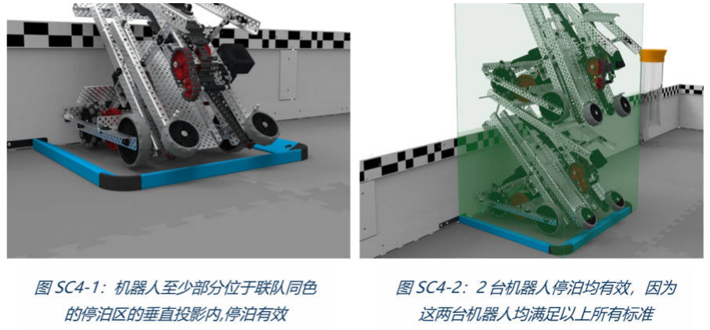
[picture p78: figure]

3 机器 制作

因为电机的使用有限制 只能使用VEX V5电机111w

和 v5电机15.5W1 如何分配电机 可以充分利用功率 来保证底盘和车辆结构的运行

总功率 88W

可能的组合 | 数量
11 W电机 | 8 | 7 | 6 | 5 | 0
5.5W电机 | 0 | 2 | 4 | 6 | 1

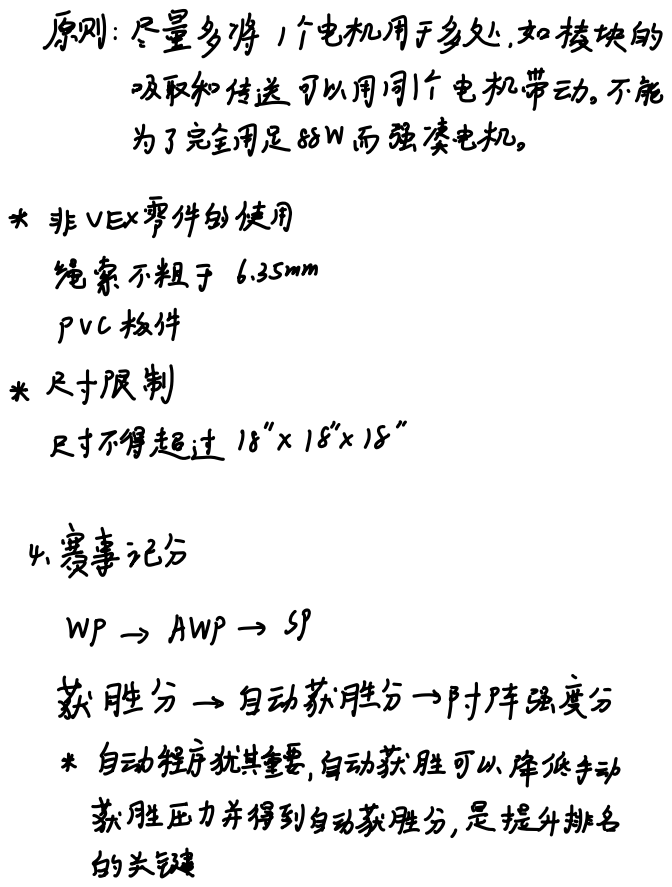
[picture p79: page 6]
非 VEX零件的使用; 绳索不粗于 6.35mm pvc 板件 尺寸限制; 尺寸不得超过 18 18 18; 4 赛事记分; AWp; 获胜分; 自动获胜分; 附阵强度分; 自动程序犹其重要 自动获胜可以降低手动; 获胜压力并得到自动获胜分 是提升排名 的 关键

原则 尽量多将 1 个电机用于多处 如 棱块 的
吸取和传送可以用同1个 电机带动 不能
为了完全用足88W 而 强凑电机

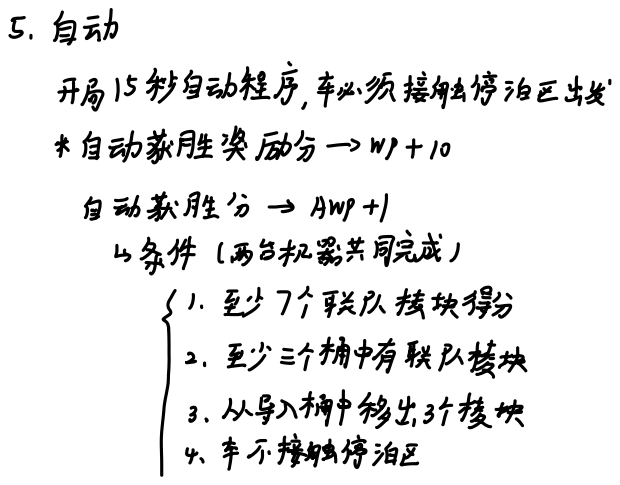
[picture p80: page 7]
自动获胜 奖励分; Awp 1; 至少三个桶中有联队棱块; 3 从导入桶中移出3个棱块 14; 车不接触停泊区

开局15秒自动程序 车必须接触停泊区出发
条件 两台机器共同完成1
1 至少 7个 联队 棱块得分

## 头脑⻛暴

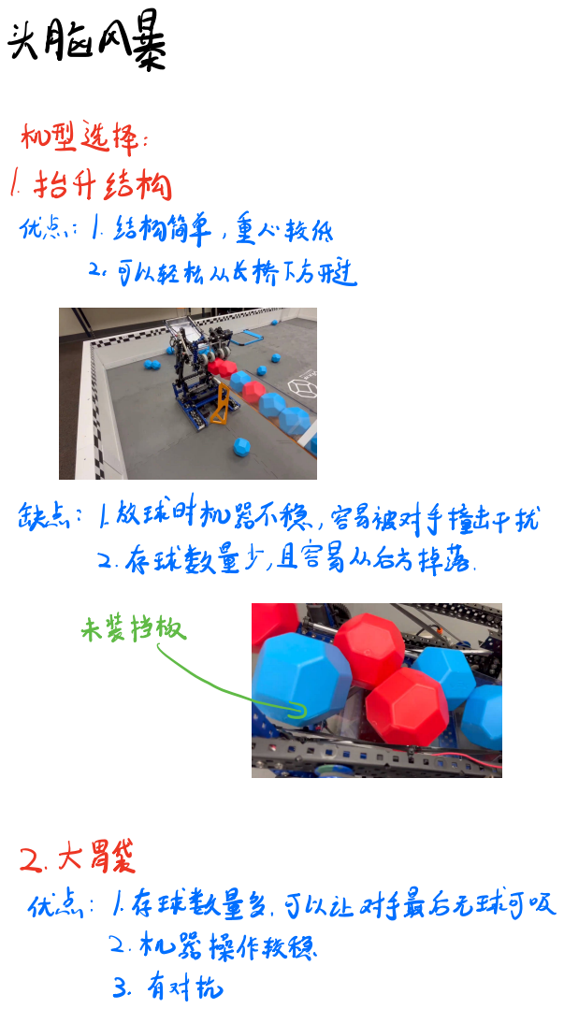
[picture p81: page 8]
未装挡板; 2 机器操作较稳 3 有对抗

机型选择
优点 1 结构简单 重⼼较低
2 可以轻松从⻓桥下⽅开过

缺点 1 放球时机器不稳 容易被对⼿撞击⼲扰
2 存球数量少 且容易从后⽅掉落

优点 1存球数量多 可以让对⼿最后⽆球可吸

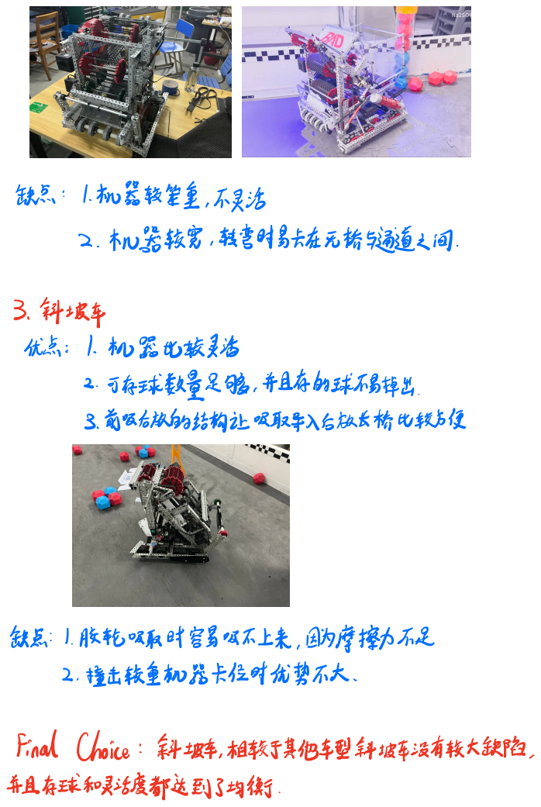
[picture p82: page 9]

缺点 1机器较笨重 不灵活
2 机器较宽 转弯时易卡在⽆桥与通道之间

优点 1 机器⽐较灵活
2 可存球数量⾜够 并且存的球不易掉出
3 前吸后放的结构让吸取导⼊后放⻓桥⽐较⽅便

缺点 1 胶轮吸取时容易吸不上来 因为摩擦⼒不⾜
2 撞击较重机器卡位时优势不⼤

Final Choice 斜坡⻋ 相较于其他⻋型斜坡⻋没有较⼤缺陷
并且存球和灵活度都达到了均衡

## 问题 修改

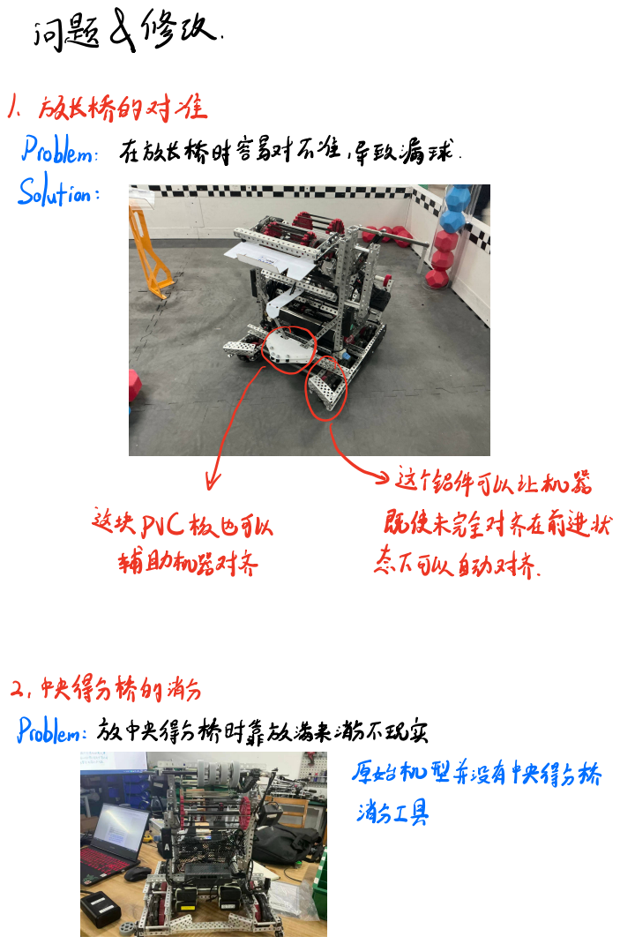
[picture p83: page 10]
⼈这个铝件可以让机器; 这块PVC板也可以; 既使未完全对⻬在前进状; 辅助机器对⻬; 态下可以⾃动对⻬; 2 中央得分桥的消分; Problem 放中央得分桥时靠放满来消分不现实; 原始机型并没有中央得分桥

1 放⻓桥的对准
Problem 在放⻓桥时容易对不准 导致漏球
Solution

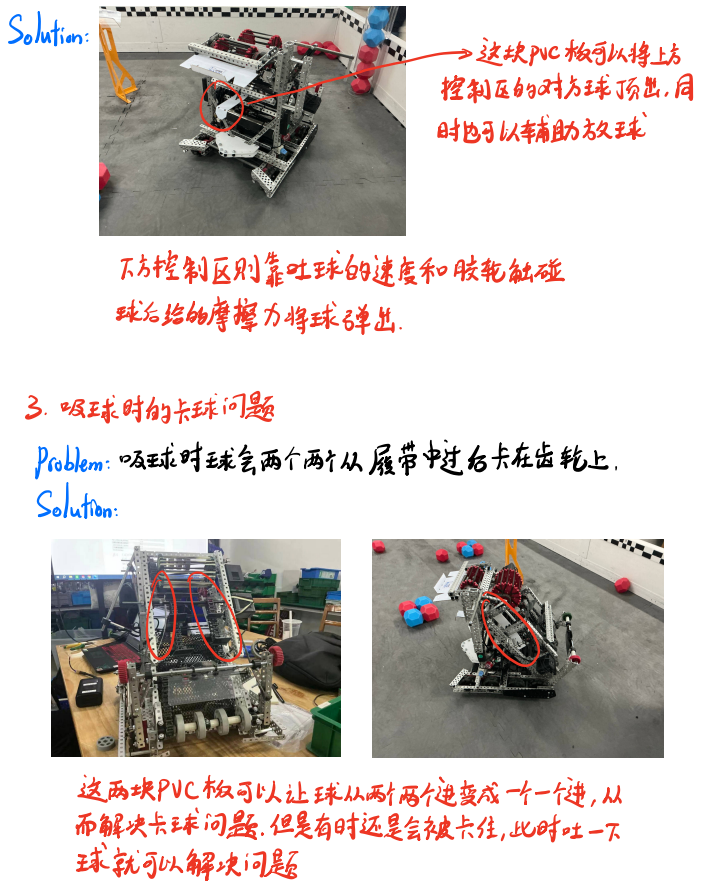
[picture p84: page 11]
Solution; 这块Pvc板可以将上⽅ 0 ⼀⼀ 扣主制区的对⽅球顶出 同; 时也可以辅助 放 球; 下⽅控制区则靠吐球的速度和胶轮触碰; 球后给的摩擦⼒将球弹出; 3 吸球时的卡球问题

Problem 吸球时球会两个两个从履带中过后卡在⻮轮上
Solution

这两块PUC板可以让 球从两个两个进变成 ⼀个⼀个进 从
⽽解决卡球问题但是有时还是会被卡住此时吐⼀下
球就可以解决问题

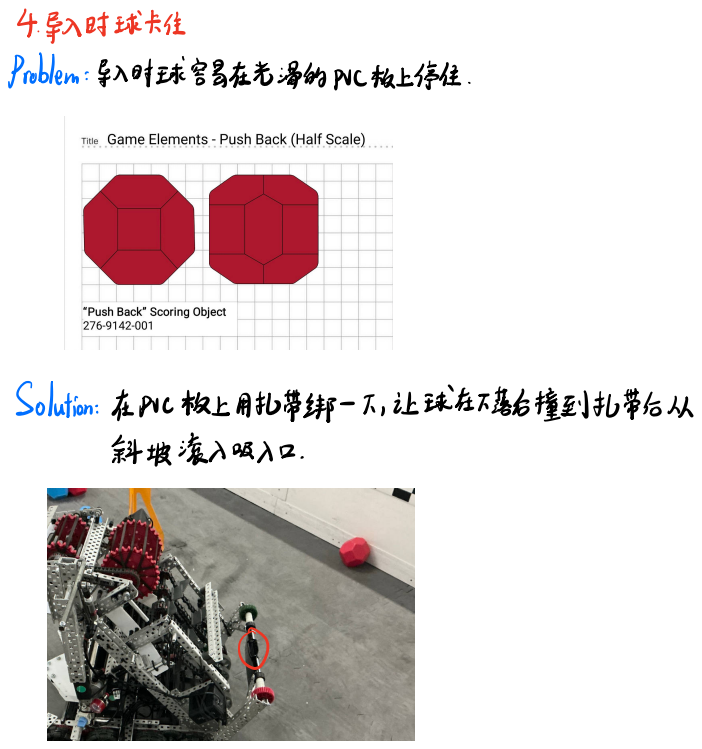
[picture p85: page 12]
4 导⼊时球卡住; Problem 导⼊时球容易在光滑的PVC板上停住; 斜坡滚⼊吸⼊⼝

Solution 在PVC板上⽤扎带绑⼀下 让 球在下落后撞到扎带后从

## 机器 设计

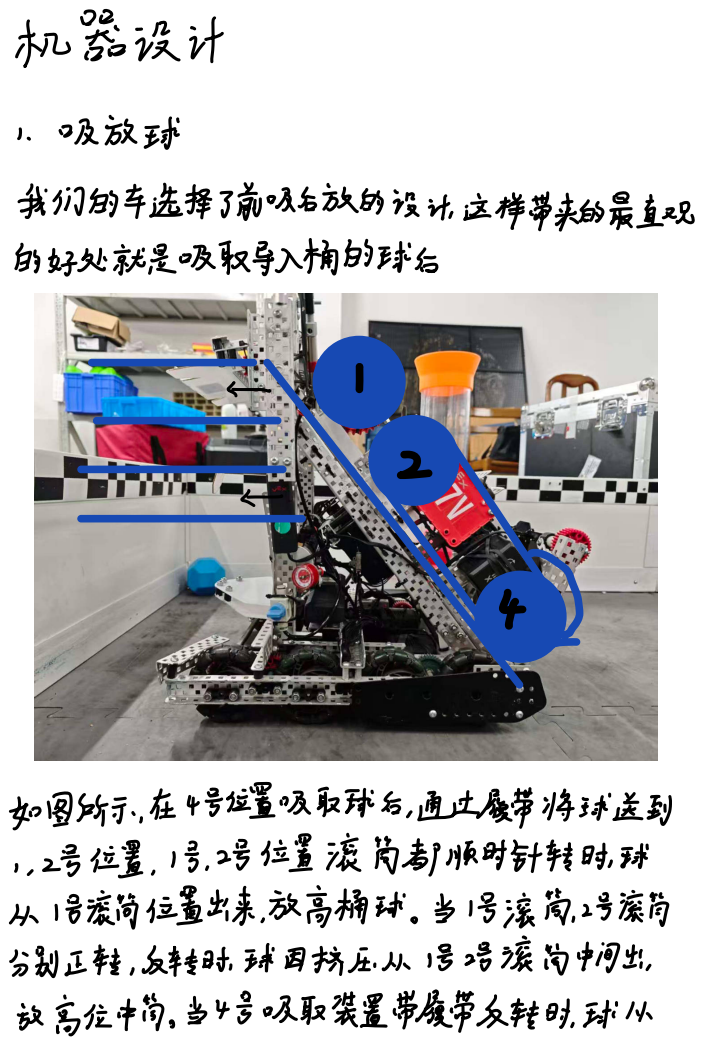
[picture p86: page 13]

我们的车选择了前吸后放的设计 这样带来的最直观
的好处 就是吸取导入桶的 球后

如图所示 在 4号位置吸取球后 通过履带将 球送到
2号位置 1号 2号位置 滚筒都顺时针转时 球
从 1号滚筒位置出来 放高桶 球 当 1号滚筒2号滚筒
分别正转 反转时 球 因挤压 从 1号 2号滚筒中间出
放 高位中筒 当4号 吸取装置带履带反转时 球 从

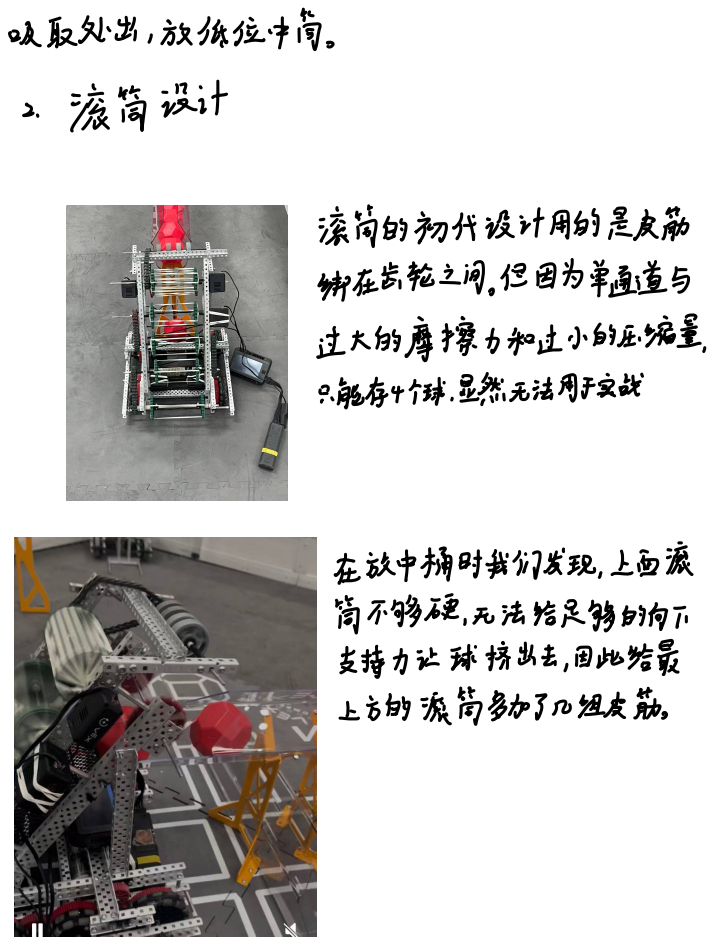
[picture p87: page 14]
吸取处出 放 低位中筒; 滚筒设计; 滚筒的 初代设计用的是皮筋; 绑在齿轮之间 但因为单通道与; 过大的摩擦力和过小的压缩量; 只能存4个球 显然无法用于实战

在放中桶时我们发现 上面滚
筒不够硬 无法 给足够的向下
支持力让 球挤出去 因此给最
上方的滚筒多加了几 组皮筋

3 吸取结构; 吸取结构最初用的是和上面一样的

皮筋滚筒 但 因为实际 测试 中发现皮筋
很容易在对抗中 被其它机器钓掉因此最后
换成了胶轮

4 链条结构; 传动的链条 也 经过 一; 次改动 为了防止链条

在比赛对抗中损坏 我们将链条的位置从车外
侧 改到 了内侧 并再加装横梁保护

1 自动的路线思路; 自动的15秒需要兼顾自动任务的 完成和后面对于手; 动对抗的优势 因此 如何高效利用15秒自动尽可; 自动任务达成; 先回顾自动任务; 至少三个桶中有联队棱块; 3 从导入桶中移出3个棱块 14; 车不接触停泊区; 因为自动任务需要队友配合 尽可能多完成; 任务就 行; 自动得分; 至少打进 1个预装 3个场上 的 球 3个导入 可以保; 证 7分得分达成

能得分并完成自动任务 同时为手动创造优势是
核心思路
伏 先极 自动任务达成 自动得分 手动优势建立

1 至少 7个 联队 棱块得分

跟距思路写的左侧自动 从路线上看是先打中桶 4封; 再吸导入并打长桶 了球最后占领控制区 实现7分得分; 2个桶有球 控制区占领的 目标

手动优势建立
控制区的抢夺是比赛的重点 如果能在自动
时段占住控制区是很大 的优势 所以路线
上应该先放中桶 再放长桶并占领控制区
左侧自动

实战中对手也 在同步得分 中桶 的 球有时

经过几次比赛的实战 经验 后 我们发现了问题

会被对面对位的 放球干扰 所以第二版我们改进了
路线 选择先 放长桶再打中桶的路线 这样可以
较大概率晚于对面放中桶 保证得分的同时还
能消掉对面的球

右侧自动; chesdb; si head; nàd; head; head dead; 仍是吸扬地球; 吸导入; 抢 控制区

右侧自动由于中桶是低处 的 我们 机器在放低桶时要
反转电机从 吸球口 放球 时间与操作上都有很大困难
我们最终决定放弃中桶 把7分全部打到长桶 整体路线

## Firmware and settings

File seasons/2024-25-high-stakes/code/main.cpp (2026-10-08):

#include "vex.h"
#include "autons.h"
#include "user.h"
// ---- START VEXCODE CONFIGURED DEVICES ----
// Robot Configuration:
// [Name]               [Type]        [Port(s)]
// Inertial             inertial      15              
// left1                motor         13              
// left2                motor         12              
// left3                motor         11              
// right1               motor         18              
// right2               motor         19              
// right3               motor         20              
// wing                 digital_out   A               
// climb1               digital_out   F               
// climb2               digital_out   H               
// shooter              motor         16              
// collectR             motor         14              
// collectL             motor         17              
// Controller1          controller                    
// ---- END VEXCODE CONFIGURED DEVICES ----

using namespace vex;
competition Competition;
int thread1=0;

int fff=0;

int display()//显示角度
{
  while(1)
  {
    Controller1.Screen.setCursor(1,1);
    Controller1.Screen.print("GYROz%.2f",Gyro.rotation());//陀螺仪
    Controller1.Screen.setCursor(1,12);
    Controller1.Screen.print("r%.2f",r.angle());
  }
}
task a = task(display);


Drive chassis(

ZERO_TRACKER_ODOM,

motor_group(leftA, leftB, leftC),

motor_group(rightA, rightB, rightC),

PORT7,//惯性传感器端口 *************

4.125,//输入轮子的直径
//4.125
//3.25
//2.75

0.5,//输入齿轮/输出齿轮算出齿轮比

360,//陀螺仪比例
//左轮前后端口     右轮前后端口
PORT10,     -PORT3,

PORT9,     -PORT2,
//下面默认就可以了
3,

2.75,

-2,

1,

-2.75,

5.5

);

int current_auton_selection = 0;
bool auto_started = false;

/**
 * Function before autonomous. It prints the current auton number on the screen
 * and tapping the screen cycles the selected auton by 1. Add anything else you
 * may need, like resetting pneumatic components. You can rename these autons to
 * be more descriptive, if you like.
 */
 void arm() {
  timer Tarm;
  double pre_angle = fabs(r.angle());
  double p = 0.8;
  double error_a;
  double speed = 0;
  double t_angle = 37;

  while (thread1 == 1) {
    if (Controller1.ButtonUp.pressing()) {
      climb.spin(forward, 100, pct);
    } else if (Controller1.ButtonDown.pressing()) {
      climb.spin(forward, -90, pct);
    } else {
      climb.stop(hold);
    }

    if (Controller1.ButtonLeft.pressing()) 
    {
      while ( r.angle() < t_angle || r.angle() > 350) 
      {
        if(r.angle()>0 && r.angle()<t_angle)
         {  
            pre_angle = r.angle();
            error_a = t_angle - pre_angle;
            speed = 20+error_a*p;
            climb.spin(fwd,speed,pct);
            
        if(Tarm > 700)
        {
          Tarm.clear();
          pre_angle = r.angle();
        }
        if(fabs(pre_angle -t_angle) < 2.5 and Tarm > 350)
        {
          break;
        }
        wait(10,msec);
        }

        else{
          climb.spin(fwd,30,pct);
         }
      }

      while (r.angle(degrees) > t_angle && r.angle() < 355) 
      {
            pre_angle = r.angle();
            error_a = t_angle - pre_angle;
            speed = error_a*0.8;
            climb.spin(fwd,speed,pct);
         if(Tarm > 700)
        {
          Tarm.clear();
          pre_angle = r.angle();
        }
        if(fabs(pre_angle -t_angle) < 3.5 and Tarm > 350)
        {
          break;
        }
        wait(10,msec);
      }
    }
  }
} 

//   void arm()
// {
//   climb.resetPosition();
//   while(1)
//   {
//      if(Controller1.ButtonX.pressing())
//     {
//       climb.spin(forward,100,pct); 
//     }
//     else if(Controller1.ButtonB.pressing())
//     {
//       climb.spin(reverse,90,pct);
//     }
//     else
//     {
//       climb.stop(hold);
//     }

//       if(Controller1.ButtonY.pressing())
//     {
//       while(climb.position(degrees)<115 )
//       {
//         climb.spin(fwd,50,pct);
//       }
//       climb.stop(hold);
//     }  

//   }

// }

thread t1(arm);

void pre_auton(void) {
  vexcodeInit();
  default_constants();
  //选择程序
  while(!auto_started){
    Brain.Screen.clearScreen();
    Brain.Screen.setFont(monoXL);
    Brain.Screen.setFillColor(purple);
    Brain.Screen.setCursor(1, 1);
    Brain.Screen.print("GYRO:%.2f",Gyro.rotation());
    switch(current_auton_selection){
      case 0:
        Brain.Screen.setFillColor(red);
        Brain.Screen.printAt(10, 120, "red you ");
        break;
      case 1:
        Brain.Screen.setFillColor(blue);
        Brain.Screen.printAt(10, 120, "blue zuo ");  
        break;
      case 2:
        Brain.Screen.setFillColor(red);
        Brain.Screen.printAt(10, 120, "red zuo ");
        break;
      case 3:
        Brain.Screen.setFillColor(blue);
        Brain.Screen.printAt(10, 120, "blue you");
        break;
    }
    if(Brain.Screen.pressing()){
      while(Brain.Screen.pressing()) {}
      current_auton_selection ++;
    } else if (current_auton_selection == 4){
      current_auton_selection = 0;
    }
    task::sleep(10);
  } 
 
}

void autonomous(void) {
  //根据选择程序进入自动程序
  thread1=0;//多线程手臂不启用
  // current_auton_selection = 2;
  switch(current_auton_selection){ 
    case 0:
      hyou_test();
      break;
    case 1:         
      lzuo_a2();
      break;
    case 2:
      test523();
      //hzuo_test();
      break;
    case 3:
      lyou();
      break; 
    }
  just_stop(0);
}

void usercontrol(void) {
   thread1=1;//启用多线程手臂
   just_stop(0);
   thread t1(arm);

  while (1) {
    chassis.control_tank();
    UserCollect();
    handle();

      if(Controller1.ButtonA.pressing())
     {
       t1.interrupt();
       //hzuo_test();
       test523();
     } 
    //按键测试，比赛开始前需要注销掉
/*      if(Controller1.ButtonRight.pressing() && fff==0)
    { thread1=0;
     
     switch(current_auton_selection){ 
    case 0:
      hyou();
      break;
    case 1:         
      lzuo();
      break;
    case 2:
      hzuo();
      break;
    case 3:
      hzuo2();
      break; 
    case 4:
      lyou();
      break;
    case 5:
      lyou2();
      break;
    }

     fff=1;thread1=1;
    }  */
}
}


int main() {
  Competition.autonomous(autonomous);
  Competition.drivercontrol(usercontrol);
  pre_auton();
  while (true) {
    wait(100, msec);
  }
  return 0;
}

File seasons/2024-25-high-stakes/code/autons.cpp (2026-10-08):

#include "vex.h"
#include "user.h"


void default_constants() {
  //调试PID参数，分别是（最大电压，KP,KI,KD,statI参数）
  chassis.set_drive_constants(10, 1.2, 0, 5, 0);
  chassis.set_heading_constants(6, 0.1, 0, 1, 0);
  chassis.set_turn_constants(10, 0.3, 0.001, 0.8, 0);
  chassis.set_swing_constants(10, .3, .001, 2, 15);

  //设置程序跳出条件（误差，时间，时间截止）都是以ms为单位的
  chassis.set_drive_exit_conditions(1.5, 180, 900);
  chassis.set_turn_exit_conditions(1, 180, 900);
  chassis.set_swing_exit_conditions(1, 180, 900);
}

void lzuo_a2()
{
  default_constants();
  chassis.drive_timeout=700;
  chassis.drive_distance(18/2.54,0,6,6);
  climb.spin(fwd,60,pct);
  wait(1,sec);
  climb.stop();
  wait(0.3,sec);
  chassis.drive_timeout=900;
  chassis.drive_distance(-35/2.54,0,6,6);
  chassis.turn_to_angle(-57,8);
  intake(100);
  chassis.drive_distance(22/2.54,-57,7,7);
  wait(0.5,sec);
  intake(0);
  //xi.spin(forward,100,pct);
  arm(-300,60, 0);

  chassis.drive_distance(-10/2.54,-57,7,7);
  chassis.turn_to_angle(5,7);
   chassis.drive_timeout=1100;
  chassis.drive_distance(-30,5,7,7);
  zhua.set(1);
  intaketime(90,1);
  
  chassis.turn_to_angle(122,8);
  intake(100);
  chassis.drive_distance(56/2.54,122,6.5,6.5);
  wait(1,sec);
  chassis.drive_distance(-56/2.54);
  wait(0.5,sec);
  intake(0);
  
  chassis.turn_to_angle(264,8);
  intake(90);
  chassis.drive_distance(24/2.54,264,7,7);
  arm(245,60,0);
  just_stop(0);
}

void test523()
{
  default_constants();
  climb.spin(fwd,60,pct);
  wait(0.8,sec);
  climb.stop();
  chassis.drive_distance(-20/2.54,0,6,6);
  chassis.turn_to_angle(-2,7);
  chassis.drive_timeout=1700;//默认timeout900
  chassis.drive_distance(-115/2.54,-2,6,6);
  zhua.set(1);
  wait(0.5,sec);
  chassis.turn_to_angle(40,7);
  intake(100);
  chassis.drive_distance(60/2.54,40,7,7);
  wait(0.5,sec);
  chassis.turn_to_angle(-97,7);
  chassis.drive_distance(78/2.54,-97,7,7);
  wait(0.5,sec);
  chassis.turn_to_angle(-170,7);
  chassis.drive_distance(60/2.54,-170,6,6);
  wait(0.5,sec);
  chassis.turn_to_angle(-20,7);
  chassis.drive_distance(60/2.54,-60,8,8);
  intake(0);
}

void test_van()
{
  default_constants();
  climb.spin(fwd,60,pct);
  wait(0.8,sec);
  climb.stop();

  chassis.drive_distance(-30/2.54,0,6,6);
  chassis.turn_to_angle(-90,8);
  chassis.drive_distance(-60/2.54,-90,6,6);
  zhua.set(1);
  chassis.turn_to_angle(180,8);
  intake(100);
  chassis.drive_distance(62/2.54,180,7,7);
  chassis.turn_to_angle(90,8);
  chassis.drive_distance(60/2.54,90,7,7);
  wait(0.5,sec);
  chassis.turn_to_angle(155,8);
  chassis.drive_distance(43/2.54,155,7,7);
  wait(0.5,sec);
  chassis.turn_to_angle(-4,8);
  chassis.drive_distance(130/2.54,-4,7,7);
  wait(0.5,sec);
  chassis.turn_to_angle(0,8);
  chassis.drive_distance(45/2.54,0,7,7);
  wait(0.5,sec);
  chassis.drive_distance(-35/2.54,0,7,7);
  chassis.turn_to_angle(90,8);
  chassis.drive_distance(30/2.54,90,7,7);
  chassis.turn_to_angle(200,8);
  chassis.drive_distance(-55/2.54,195,7,7);
  zhua.set(0);
}

void hyou_a2()
{
  default_constants();
  chassis.drive_timeout=700;
  chassis.drive_distance(20/2.54,0,6,6);
  climb.spin(fwd,60,pct);
  wait(1,sec);
  climb.stop();
  wait(0.3,sec);
  chassis.drive_timeout=900;
  chassis.drive_distance(-35/2.54,0,6,6);
  chassis.turn_to_angle(57,8);
  xi.spin(fwd,-100,pct);//第一层电机
  xi2.spin(fwd,-100,pct);//第二层电机
  chassis.drive_distance(22/2.54,57,7,7);
  wait(0.5,sec);
  intake(0);
  // xi.spin(forward,100,pct);
  arm(-350,60, 0);

  chassis.drive_distance(-10/2.54,57,7,7);
  chassis.turn_to_angle(-5,7);
  chassis.drive_timeout=1100;
  chassis.drive_distance(-30,-5,7,7);
  zhua.set(1);
  intaketime(90,1);
  
  chassis.turn_to_angle(-122,8);
  intake(100);
  chassis.drive_distance(50/2.54,-122,6.5,6.5);
  wait(1,sec);
  chassis.drive_distance(-50/2.54);
  intake(0);//取消intake
  
  chassis.turn_to_angle(-264,8);
  chassis.drive_distance(23/2.54,-264,8,8);
  arm(220,60,0);
  just_stop(0);
}

void hyou_testnew()
{
  default_constants();
  chassis.drive_timeout=700;
  climb.spin(fwd,60,pct);
  wait(0.8,sec);
  climb.stop();
  wait(0.3,sec);
  chassis.drive_timeout=900;
  chassis.drive_distance(-20/2.54,0,8,8);
  chassis.turn_to_angle(60,8);
  chassis.drive_distance(35/2.54,57,8,8);
  xi.spin(fwd,-100,pct);
  wait(0.7,sec);
  intake(0);
  arm(-350,60, 0);

  chassis.turn_to_angle(-25,8);
  chassis.drive_timeout=1700;
  chassis.drive_distance(-75/2.54,-25,8,8);
  zhua.set(1);
  wait(0.5, sec);
  chassis.turn_to_angle(-155,8);
  intake(100);
  chassis.drive_distance(65/2.54,-155,9,9);
  chassis.turn_to_angle(-85,8);
  zhua2.set(1);
  chassis.drive_distance(80/2.54,-85,8,8);
  chassis.turn_to_angle(-173,10);
  zhua2.set(0);
  chassis.drive_distance(20/2.54,-173,10,10);
  chassis.drive_distance(-20/2.54,-173,10,10);
  chassis.turn_to_angle(-263,8);
  chassis.drive_distance(140/2.54,-263,10,10);
  just_stop(0);
}

void hyou_test()
{
  default_constants();
  //chassis.drive_timeout=700;
  //chassis.drive_distance(20/2.54,0,6,6);
  climb.spin(fwd,60,pct);//什么意思？？？
  wait(0.5,sec);
  climb.stop();
  wait(0.3,sec);
  chassis.drive_timeout=900;
  chassis.drive_distance(-35/2.54,0,8,8);
  chassis.turn_to_angle(57,8);
  xi.spin(fwd,-100,pct);//第一层电机？？
  xi2.spin(fwd,-100,pct);//第二层电机？？
  chassis.drive_distance(22/2.54,57,8,8);
  wait(0.5,sec);
  intake(0);
  // xi.spin(forward,100,pct);
  arm(-350,60,0);

  chassis.drive_distance(-10/2.54,57,8,8);
  chassis.turn_to_angle(-5,8);
  chassis.drive_timeout=1100;
  chassis.drive_distance(-30,-5,8,8);
  zhua.set(1);
  intaketime(90,0.5);
  
  chassis.turn_to_angle(-122,8);
  intake(100);
  chassis.drive_distance(53/2.54,-122,8,8);
  wait(0.3,sec);
  
  //加转向去清角
  //chassis.drive_distance(-50/2.54);
  intake(0);//取消intake
  
  chassis.turn_to_angle(-264,8);
  chassis.drive_distance(23/2.54,-264,8,8);
  arm(220,60,0);
  just_stop(0);
}

void test228()
{
  //车45cm，一格垫子60cm
  default_constants();
  chassis.drive_distance(-55/2.54,0,7,7);//滚轮一侧是头
  zhua.set(1);
  wait(1,sec);
  chassis.drive_distance(-10/2.54,0,7,7);
  chassis.turn_to_angle(90,8);
  intake(100);
  chassis.drive_distance(62/2.54,90,8,8);
  wait(2,sec);//让吸持续
  //just_stop(0);
}
void test1(){

  chassis.drive_distance(40/2.54,0,10,10);
  chassis.turn_to_angle(90,10);
  wait (1,sec);
  chassis.drive_distance(40/2.54,90,10,10);
  chassis.turn_to_angle(180,10);
  wait (1,sec);
  chassis.drive_distance(40/2.54,180,10,10);
  chassis.turn_to_angle(270,10);
  wait (1,sec);
  chassis.drive_distance(40/2.54,270,10,10);
  chassis.turn_to_angle(0,10);
} 
void test2(){
 default_constants();
  arm(450,90,1);
  chassis.drive_distance(26/2.54,0,8,8);
  
   arm(90,90,1);
  
  chassis.drive_distance(-75/2.54,10,7,7);
  zhua.set(1);
  chassis.turn_to_angle(-14,10);
  arm(-540, 90, 0);
  chassis.drive_distance(80/2.54,-14,10,10);
  intake(100);
  wait(1, sec);
  intake(0);
}
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

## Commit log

2026-10-08 VEX Robotics: four seasons, from newcomer to captain (v1)
    Four seasons of VEX V5 at SFLS (2023-27): the 2025-26 design log
    (Gen 1 -> Gen 2 -> Gen 3), autonomous code for 2024-25 and 2025-26,
    the full engineering notebook and design documents, build guides,
    custom SolidWorks parts, photos, and what being captain involved.
    [17孔粗轴.SLDPRT, de.SLDPRT, sled-V2.SLDPRT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]
2026-10-08 Add event photos: Suzhou team photo, Huzhou match and stage
